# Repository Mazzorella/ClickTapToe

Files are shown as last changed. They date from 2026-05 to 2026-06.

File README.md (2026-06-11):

# ClickTapToe

ClickTapToe is a custom foot-operated mouse for people who need to reduce repetitive hand and arm movement. The goal is to move common mouse actions away from the hands by using foot pedals for clicking, a large foot-driven scroll wheel, and a separate mouse pointer module.

This repository contains the firmware, hardware notes, and project documentation for ClickTapToe. The current firmware target is a Seeed Studio XIAO nRF52840 / XIAO BLE running as a USB HID mouse with ZMK. Bluetooth is disabled for the ClickTapToe firmware build.

## Current Status

The current firmware supports USB mouse clicks from external pedals, USB vertical scrolling from the input hub scroll wheel, and pointer movement from the mouse pointer module:

- Left click on the first pedal input
- Right click on the second pedal input
- Vertical scroll from the AS5600 magnetic angle sensor connected to the input hub scroll wheel
- Pointer movement from the PMW3610 sensor in the mouse pointer module
- `D2` and `D3` remain spare/test inputs and are not exposed as production pedal jacks on the current input hub PCB

PMW3610 pointing support is active for the current firmware target.

## Hardware Overview

ClickTapToe is built from two custom electronics modules plus external pedals:

- The input hub contains the XIAO nRF52840 controller, USB connection, external pedal TS jacks, RJ45 pointer connection, and a large foot-operated scroll wheel coupled to an AS5600 magnetic angle sensor.
- The mouse pointer module is shaped like a slipper, houses a PMW3610 pointing sensor, and connects to the input hub over RJ45 with a short Ethernet cable.
- The pedals are premade external pedals connected to the input hub so higher-quality parts can be used and the project is easier to reproduce.

See [HARDWARE.md](HARDWARE.md) for the current pin map and hardware notes.
For a public-facing hardware overview with embedded board previews, open the
[ClickTapToe Hardware Viewer](https://mazzorella.github.io/ClickTapToe/).

| Board | Source | KiCanvas preview |
| --- | --- | --- |
| Input hub | [hardware/input-hub/](hardware/input-hub/) | [Open preview](https://mazzorella.github.io/ClickTapToe/hardware/input-hub/kicanvas.html) |
| Mouse pointer | [hardware/mouse-pointer/](hardware/mouse-pointer/) | [Open preview](https://mazzorella.github.io/ClickTapToe/hardware/mouse-pointer/kicanvas.html) |

## Repository Layout

- `.github/workflows/build.yml` runs the upstream ZMK user-config build workflow.
- `build.yaml` defines the firmware build matrix.
- `config/west.yml` tracks upstream ZMK and imports ZMK's west manifest.
- `zephyr/module.yml` declares this repository as the `zmk-keyboard-clicktaptoe` module and exposes its board, devicetree binding, Kconfig, and driver files.
- `boards/shields/clicktaptoe/` contains the ClickTapToe shield definition, overlay, metadata, and default keymap.
- `Makefile` wraps the local `west build` command for Docker/devcontainer use.
- `hardware/` contains the input hub and mouse pointer KiCad source files.
- `docs/` is reserved for assembly, usage, and release documentation.

## Build Target

The active firmware target is:

```yaml
board: xiao_ble//zmk
shield: clicktaptoe
artifact-name: clicktaptoe_xiao_usb_zmk
```

## Flashing

1. Build the firmware with GitHub Actions or a local ZMK toolchain.
2. Put the XIAO BLE into bootloader mode so it mounts as a UF2 drive.
3. Copy the generated `clicktaptoe_xiao_usb_zmk.uf2` file onto the mounted drive.
4. After the board reboots, connect it to the host over USB.

## Hardware Test

Use a safe desktop target for click testing, such as an empty Finder window or browser page.

- Short physical `D0` to `GND`; the host should receive a left click.
- Short physical `D1` to `GND`; the host should receive a right click.
- Rotate the AS5600 scroll wheel; the host should receive vertical scroll events.
- Move the mouse pointer module over a surface; the host pointer should move smoothly in the same direction.
- Test the PMW3610 once through the RJ45 cable path; pointer response should match the direct breadboard wiring test.
- Leave the AS5600 magnet away from the sensor once as a negative test; the host should not scroll continuously.
- Verify `D2` and `D3` only as spare/test GPIOs if they are wired for bring-up.

If macOS does not immediately recognize the updated HID device, unplug and reconnect the XIAO BLE.
If an old Bluetooth name appears after flashing, remove the cached Bluetooth entry from the host. This firmware build disables ZMK BLE.
If the PMW3610 does not move the pointer after flashing, power-cycle the XIAO once. The input hub physically routes PMW3610 `nRESET` on XIAO `D6` / RJ45 pin 8, but the current firmware still relies on SPI/software reset and does not drive that reset line yet.

## Local Build Notes

This repository is both a ZMK config repository and a ZMK module. Local builds should make the repository visible to ZMK as the config path and as an extra module so the custom `clicktaptoe` shield can be discovered.

The preferred local workflow is to build from a ZMK Docker/devcontainer environment and use this repository's `Makefile`.

One common local layout is to keep this repository next to a ZMK firmware checkout:

```text
projects/
  zmk/
  zmk-pmw3610-driver/
  ClickTapToe/
```

Open the ZMK firmware checkout in VS Code:

```sh
code /path/to/projects/zmk
```

Then use **Dev Containers: Reopen in Container**. If using a devcontainer, bind mount this repository into the container and run the build commands from the ClickTapToe repository directory.

On the first devcontainer launch, initialize the Zephyr workspace from the ZMK checkout:

```sh
west init -l app/
west update
```

Restart the devcontainer after `west update` completes.

Clone the PMW3610 driver module where the `Makefile` can find it. In the default devcontainer layout:

```sh
git clone https://github.com/badjeff/zmk-pmw3610-driver /workspaces/zmk-pmw3610-driver
```

After that, run the build commands from this repository:

```sh
make build
```

To build and copy the generated UF2 into this repository's `firmware/` directory:

```sh
make uf2
```

The copied firmware path is:

```sh
firmware/clicktaptoe_xiao_usb_zmk.uf2
```

Build outputs are written under this repository's ignored `build/` directory,
not under ZMK's `app/` tree.

By default, the `Makefile` expects ZMK's app directory to be available at `../zmk/app`, which matches the sibling directory layout shown above. Override `ZMK_APP` if your checkout path differs:

```sh
make uf2 ZMK_APP=/path/to/zmk/app
```

The wrapped `west` command has this shape:

```sh
west build -d "/path/to/this-repo/build/clicktaptoe" -b "xiao_ble//zmk" -- \
  -DSHIELD=clicktaptoe \
  -DZMK_CONFIG="/path/to/this-repo/config" \
  -DZMK_EXTRA_MODULES="/path/to/this-repo;/path/to/zmk-pmw3610-driver"
```

By default, the `Makefile` expects the PMW3610 driver module at `../zmk-pmw3610-driver`. Override `PMW3610_MODULE` if your checkout path differs:

```sh
make uf2 PMW3610_MODULE=/path/to/zmk-pmw3610-driver
```

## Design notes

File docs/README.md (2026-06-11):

# ClickTapToe Docs

This folder is reserved for project-level documentation such as assembly notes,
flashing instructions, bill of materials notes, and release documentation.

- [NEXT_STEPS.md](NEXT_STEPS.md) tracks deferred software and hardware follow-up
  work after the PCB hardware branch is merged back to `main`.

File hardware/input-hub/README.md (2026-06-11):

# Input Hub Hardware

This folder contains source files and notes for the ClickTapToe input hub PCB.

The input hub is the central electronics board. It hosts the XIAO nRF52840,
connects to the computer over USB, receives the external pedal TS jacks,
connects to the mouse pointer board over RJ45, and interfaces with the AS5600
scroll sensor.

## XIAO Pin Test Plan

This validation plan keeps the existing click pedals on `D0`/`D1`, uses the
AS5600 scroll sensor on the `D4`/`D5` I2C bus, and leaves the PMW3610 SPI
signals unchanged.

| XIAO pin | Signal plan | Firmware status |
| --- | --- | --- |
| `D0` | Left click pedal | Implemented |
| `D1` | Right click pedal | Implemented |
| `D2` | Future footswitch / TTS / spare input | Test direct GPIO input, emits play/pause |
| `D3` | Future footswitch / TTS / spare input | Test direct GPIO input, emits volume up |
| `D4` | AS5600 I2C bus | Implemented as `&xiao_i2c` |
| `D5` | AS5600 I2C bus | Implemented as `&xiao_i2c` |
| `D6` | PMW3610 `nRESET` | Implemented as active-low hardware reset |
| `D7` | PMW3610 `MOTION` | Implemented as PMW3610 interrupt |
| `D8` / `P1.13` | PMW3610 `SCLK` | Implemented |
| `D9` / `P1.14` | PMW3610 `nCS` | Implemented |
| `D10` / `P1.15` | PMW3610 `SDIO` | Implemented |

## Mouse Pointer RJ45 Pinout

The mouse pointer connector is an 8P8C modular jack used for ClickTapToe sensor
wiring. It is not Ethernet. The input hub RJ45 wiring must match the mouse
pointer board exactly.

| RJ45 pin | Signal | Input hub side |
| --- | --- | --- |
| 1 | `VIN` / `3V3` | 3.3 V sensor power |
| 2 | `GND` | Ground |
| 3 | `SCLK` | PMW3610 SPI clock |
| 4 | `SDIO` | PMW3610 bidirectional SPI data |
| 5 | `nCS` | PMW3610 chip select |
| 6 | `GND` | Ground |
| 7 | `MOTION` | PMW3610 motion interrupt |
| 8 | `nRESET` | PMW3610 reset routed to XIAO `D6` |

Twisted pair grouping:

| Pair | RJ45 pins | Signals |
| --- | --- | --- |
| Pair 1 | 1-2 | `VIN` / `3V3` + `GND` |
| Pair 2 | 3-6 | `SCLK` + `GND` |
| Pair 3 | 4-5 | `SDIO` + `nCS` |
| Pair 4 | 7-8 | `MOTION` + `nRESET` |

Series resistors for `SCLK`, `SDIO`, `nCS`, and `nRESET` belong on the input hub
side. The mouse pointer board only adds a local 100 ohm series resistor on
`MOTION`, and the input hub provides the `MOTION` pull-up to `3V3`.

`MOTION` is active-low and is handled by firmware on XIAO `D7`; the board also
has a 10k pull-up to `3V3` on that line.
`nRESET` is present in the cable on RJ45 pin 8 and is driven by firmware on XIAO
`D6` during PMW3610 initialization and retry.

## Online Review

`kicanvas.html` embeds the schematic and PCB in KiCanvas for browser-based
review. If GitHub Pages is enabled from the repository root, the input hub
viewer is available at:

```text
https://mazzorella.github.io/ClickTapToe/hardware/input-hub/kicanvas.html
```

## Planned Layout

- `kicad/` for KiCad project source files
- `kicad/production/` for generated Gerbers, drill files, BOMs, and placement files

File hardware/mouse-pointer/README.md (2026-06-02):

# Mouse Pointer Hardware

This folder contains source files and notes for the ClickTapToe mouse pointer
PCB.

The mouse pointer board contains the optical pointing sensor and connects to the
input hub over RJ45.

The initial KiCad source for this board is derived from the PMW3610 breakout by
`siderakb/pmw3610-pcb`. The current ClickTapToe revision preserves the original
PMW3610 optical/lens/LDO section while adding the project-specific RJ45 cable
interface.

Mouse Pointer 1.0 is the first ClickTapToe-maintained production revision of
this board.

## RJ45 Pinout

The connector is an 8P8C modular jack used for ClickTapToe sensor wiring. It is
not Ethernet.

| RJ45 pin | Signal | Notes |
| --- | --- | --- |
| 1 | `VIN` / `3V3` | Sensor board input power |
| 2 | `GND` | Ground return |
| 3 | `SCLK` | PMW3610 SPI clock |
| 4 | `SDIO` | PMW3610 bidirectional SPI data |
| 5 | `nCS` | PMW3610 chip select |
| 6 | `GND` | Ground return paired with `SCLK` |
| 7 | `MOTION` | Active-low PMW3610 motion output after local series resistor |
| 8 | `nRESET` | Reset routed from the input hub through a 0 ohm link |

Twisted pair grouping:

| Pair | RJ45 pins | Signals |
| --- | --- | --- |
| Pair 1 | 1-2 | `VIN` / `3V3` + `GND` |
| Pair 2 | 3-6 | `SCLK` + `GND` |
| Pair 3 | 4-5 | `SDIO` + `nCS` |
| Pair 4 | 7-8 | `MOTION` + `nRESET` |

## Board Configuration

- Default logic configuration is 3.3 V: `JP1` is a 0 ohm link from `VIN` to
  `VDDIO` and is installed by default.
- Alternate 1.8 V logic is available by populating `JP2`, a 0 ohm link from
  `+1V8` to `VDDIO`. `JP2` is DNP by default.
- `JP3` is a 0 ohm reset link from RJ45 `nRESET` to PMW3610 `nRESET` and is
  installed by default.
- `R3` is a 100 ohm series resistor on `MOTION`, placed near the PMW3610 side
  before the signal leaves the board.
- `R2` is a 100k optional `nCS` pull-up to `VDDIO` and is DNP by default.
- `J1` remains as a debug/test header on the PMW3610-side signals.
- `U3` and `U4` are TPD4E05U06DQAR ESD protection arrays on the RJ45-facing
  cable signals.

The RJ45 connector is unshielded and is intended for hand installation. `J1` is
also optional/test-only and is not assigned a JLCPCB part number in the
production BOM.

The current firmware handles `MOTION` on XIAO `D7` through RJ45 pin 7 and
pulses `nRESET` on XIAO `D6` through RJ45 pin 8 before PMW3610 initialization.

## Online Review

`kicanvas.html` embeds the schematic and PCB in KiCanvas for browser-based
review. If GitHub Pages is enabled from the repository root, the mouse pointer
viewer is available at:

```text
https://mazzorella.github.io/ClickTapToe/hardware/mouse-pointer/kicanvas.html
```

## Planned Layout

- `kicad/` for KiCad project source files
- `production/` for generated Gerbers, drill files, BOMs, and placement files

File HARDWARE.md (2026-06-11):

# ClickTapToe Hardware Notes

This file tracks the hardware assumptions used by the firmware.

## Controller

- Controller: Seeed Studio XIAO nRF52840 / XIAO BLE
- ZMK board target: `xiao_ble//zmk`
- Connection mode: USB HID; ZMK BLE disabled

## Current Pedal Inputs

The current firmware uses direct GPIO inputs. Yamaha-style pedals short the
signal pin to `GND` at rest and open when pressed, so the firmware enables
internal pull-ups and treats the inputs as active-high.

For the next input hub PCB revision, add an optional 0 ohm jumper from each
pedal jack's tip-normal contact to `GND`. Populate this jumper for normally
closed Yamaha-style pedals so an unplugged jack is forced idle instead of
looking like a pressed pedal. Leave it DNP for normally open pedals and use the
matching active-low firmware polarity.

Known jack normal contacts:

| Jack type | Routed signal contact | Normal contact to optionally ground |
| --- | --- | --- |
| 1/4 inch Amphenol `ACJM-IH` | `T` / tip | `TN` / tip-normal |
| 3.5 mm `PJ-307` | Pin 5 | Pin 4 |

| Function | XIAO pin | ZMK binding | Status |
| --- | --- | --- | --- |
| Left click pedal | `D0` | `&mkp LCLK` | Implemented |
| Right click pedal | `D1` | `&mkp RCLK` | Implemented |
| Future footswitch / TTS / spare input | `D2` | `&kp C_PLAY_PAUSE` | Test direct GPIO input |
| Future footswitch / TTS / spare input | `D3` | `&kp C_VOL_UP` | Test direct GPIO input |

## Current Scroll Input

The current firmware supports vertical scroll with an AS5600 magnetic angle
sensor in the input hub. The scroll wheel spins freely with a diametric magnet
mounted on the wheel shaft near the sensor.

| Function | XIAO pin | Status |
| --- | --- | --- |
| AS5600 I2C bus | `D4` | Implemented as `&xiao_i2c` |
| AS5600 I2C bus | `D5` | Implemented as `&xiao_i2c` |
| AS5600 `VCC` | `3V3` | Board routed |
| AS5600 `GND` | `GND` | Board routed |

The AS5600 uses fixed I2C address `0x36`. ZMK is configured with
`triggers-per-rotation = <24>` as the starting scroll sensitivity for bring-up;
this should be tuned once the wheel, shaft, magnet, and sensor are mounted in
their final positions.

## Current Pointing Input

The current firmware supports PMW3610 pointing from the mouse pointer module over the XIAO SPI bus. The PMW3610 uses a bidirectional `SDIO` pin, so firmware maps both SPI MOSI and MISO to XIAO `D10`.

| Function | XIAO pin | PMW3610 pin | RJ45 pin / color | Status |
| --- | --- | --- | --- | --- |
| Sensor power | `3V3` | `VIN` / `VDDIO` default | `1` / white-orange | Board routed |
| Sensor ground | `GND` | `GND` | `2` / orange, `6` / green | Board routed |
| SPI clock | `D8` / `P1.13` | `SCLK` | `3` / white-green | Board routed |
| SPI data | `D10` / `P1.15` | `SDIO` | `4` / blue | Board routed |
| Chip select | `D9` / `P1.14` | `nCS` | `5` / white-blue | Board routed |
| Motion interrupt | `D7` / `P1.12` | `MOTION` | `7` / white-brown | Board routed |
| Sensor reset | `D6` | `nRESET` | `8` / brown | Board routed; current firmware uses SPI/software reset |

The mouse pointer module connects to the input hub through an 8P8C modular jack
used as a ClickTapToe sensor cable, not Ethernet. The cable pairing is:

| Pair | RJ45 pins | Signals |
| --- | --- | --- |
| Pair 1 | 1-2 | `VIN` / `3V3` + `GND` |
| Pair 2 | 3-6 | `SCLK` + `GND` |
| Pair 3 | 4-5 | `SDIO` + `nCS` |
| Pair 4 | 7-8 | `MOTION` + `nRESET` |

The PMW3610 orientation is corrected in firmware with `swap-xy` and `invert-y`.
The mouse pointer board routes `nRESET` over RJ45, and the input hub connects it
to XIAO `D6`. The input hub also provides a 10k pull-up to `3V3` on the
active-low `MOTION` interrupt line. This validated firmware build keeps the
original PMW3610 driver behavior and relies on SPI/software reset; D6 is routed
for a later hardware-reset recovery update.

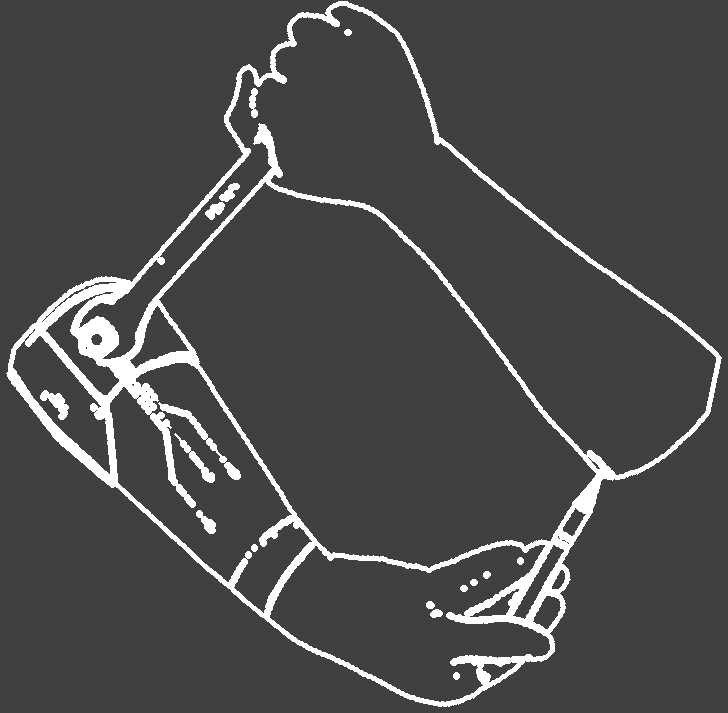
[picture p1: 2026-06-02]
hardware/input-hub/kicad/assets/empower-hand-line-silkscreen-mildsmooth.png

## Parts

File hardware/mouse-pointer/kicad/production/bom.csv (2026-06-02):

Designator | Footprint | Quantity | Value | LCSC Part #
C1 | 0805 | 1 | 3.3uF/16V | C7393948
C2, C3, C4 | 0603 | 3 | 100nF | C14663
C5, C7 | 0603 | 2 | 10nF | C57112
C6 | 0805 | 1 | 10uF | C15850
C8, C9 | 0603 | 2 | 1uF | C15849
JP1, JP3 | 0603 | 2 | 0R | C21189
R1 | 0603 | 1 | 10k | C25804
R3 | 0603 | 1 | 100 | C22775
U1 | PMW3610DM-SUDU 16Pin | 1 | PMW3610 | C42442560
U2 | SOT-23-5_HandSoldering | 1 | TLV74318PDBVR | C485152
U3, U4 | IC_TPD4E05U06DQAR | 2 | TPD4E05U06DQAR | C138714

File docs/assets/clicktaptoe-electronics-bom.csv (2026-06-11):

Quantity | Value | Footprint | LCSC Part # | Used on
4 | 1u | 0603 | C15849 | Input hub C1 C3; mouse pointer C8 C9
2 | 10uF | 0805 | C15850 | Input hub C2; mouse pointer C6
1 | 1206L012WR | 1206 | C151160 | Input hub F1
1 | B2B-PH-SM4-TB | JST_PH_B2B-PH-SM4-TB_1x02-1MP_P2.00mm_Vertical | C160352 | Input hub J11
1 | BM04B-SRSS-TB_LF__SN_ | JST_BM04B-SRSS-TB_LF__SN_ | C160390 | Input hub J5
2 | 330 | 0603 | C23138 | Input hub R1 R2
3 | 47R | 0603 | C23182 | Input hub R3 R4 R5
2 | 100 | 0603 | C22775 | Input hub R6; mouse pointer R3
4 | 10k | 0603 | C25804 | Input hub R7 R8 R9; mouse pointer R1
4 | TPD4E05U06DQAR | IC_TPD4E05U06DQAR | C138714 | Input hub U2 U3; mouse pointer U3 U4
1 | 3.3uF/16V | 0805 | C7393948 | Mouse pointer C1
3 | 100nF | 0603 | C14663 | Mouse pointer C2 C3 C4
2 | 10nF | 0603 | C57112 | Mouse pointer C5 C7
2 | 0R | 0603 | C21189 | Mouse pointer JP1 JP3
1 | PMW3610 | PMW3610DM-SUDU 16Pin | C42442560 | Mouse pointer U1
1 | TLV74318PDBVR | SOT-23-5_HandSoldering | C485152 | Mouse pointer U2

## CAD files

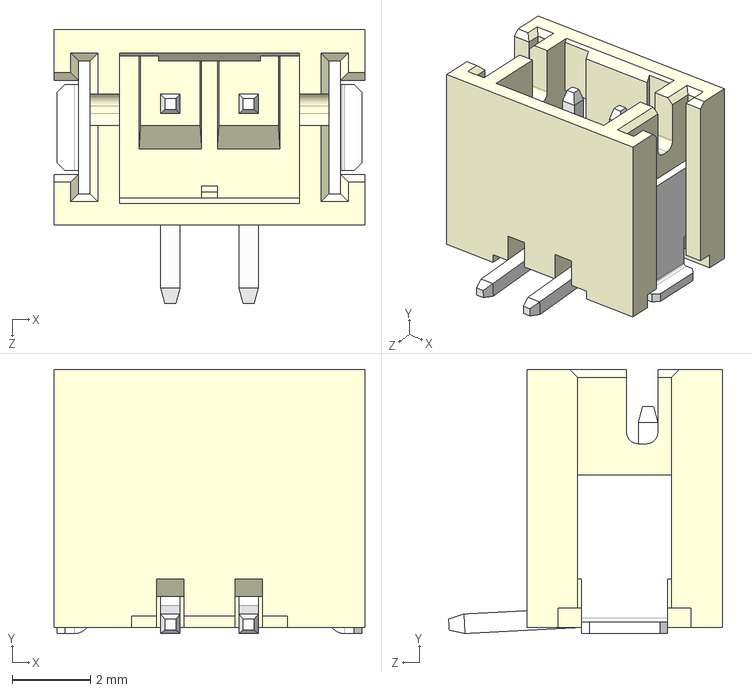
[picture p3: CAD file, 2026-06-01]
hardware/input-hub/kicad/3dmodels/B2B-PH-SM4-TB.step
7.95 x 6.75 x 7.00 mm

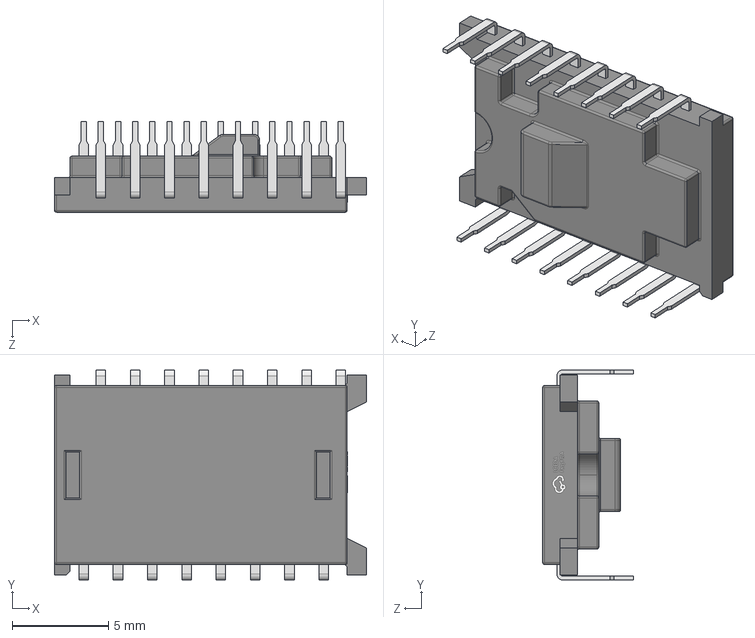
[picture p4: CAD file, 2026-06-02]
hardware/mouse-pointer/kicad/3dmodels/PMW3610DM-SUDU.step
16.2 x 10.9 x 4.70 mm

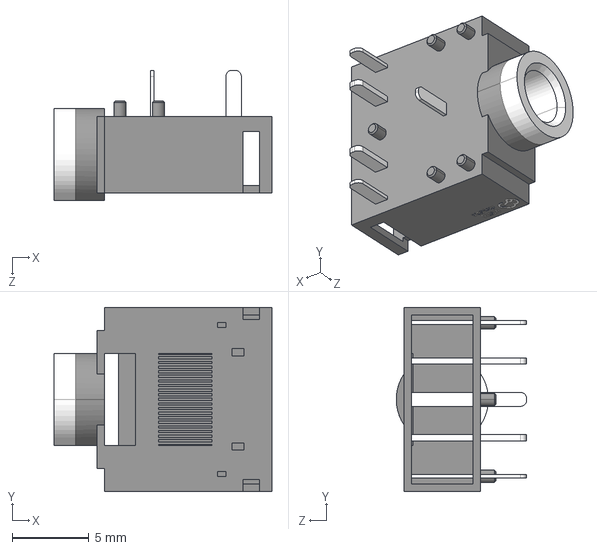
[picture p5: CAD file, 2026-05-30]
hardware/input-hub/kicad/3dmodels/AUDIO-TH_PJ-307.step
14.2 x 12.0 x 8.50 mm

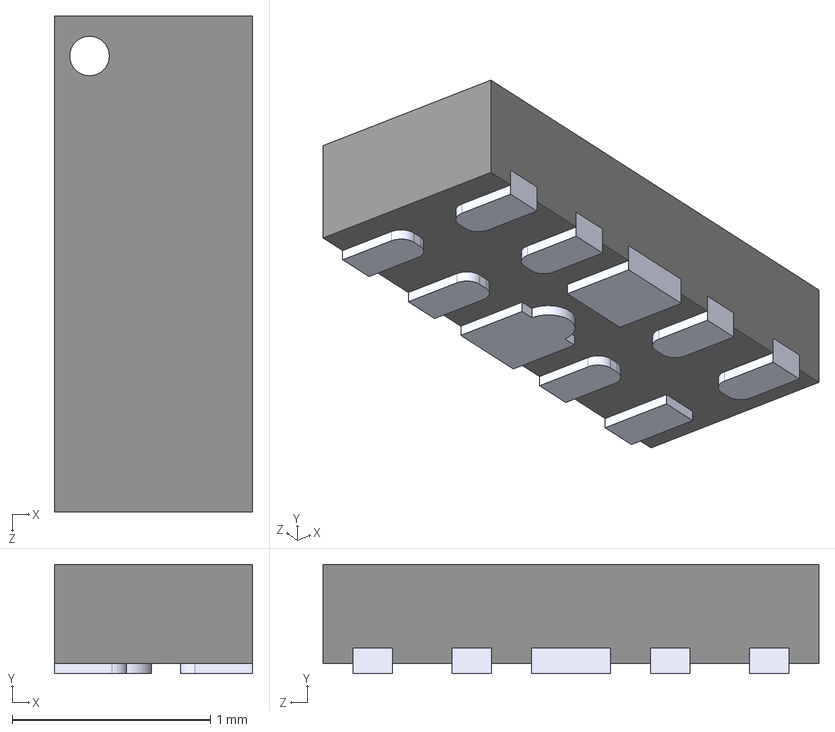
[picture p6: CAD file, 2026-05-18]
hardware/mouse-pointer/kicad/3dmodels/TPD4E05U06DQAR.step
1.00 x 0.55 x 2.50 mm

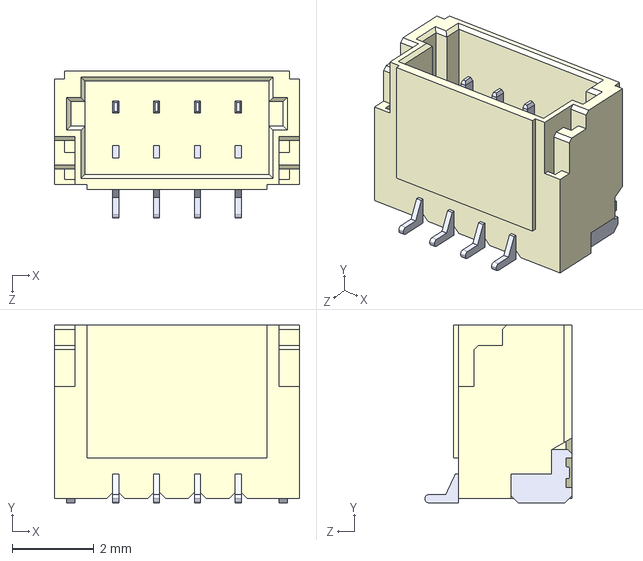
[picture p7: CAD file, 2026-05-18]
hardware/input-hub/kicad/3dmodels/BM04B-SRSS-TB_LF__SN_.step
6.00 x 4.35 x 3.60 mm

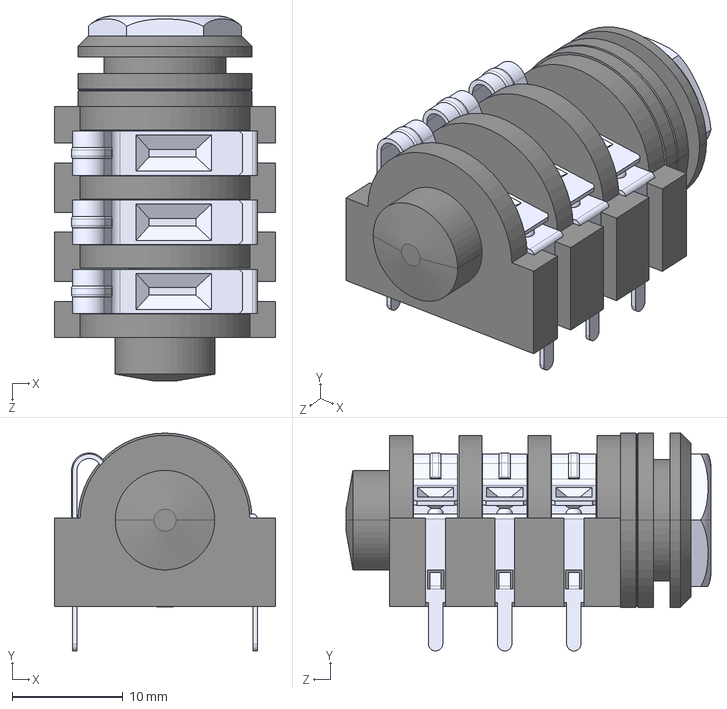
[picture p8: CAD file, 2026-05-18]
hardware/input-hub/kicad/3dmodels/ACJMIH.step
20.0 x 19.7 x 33.0 mm

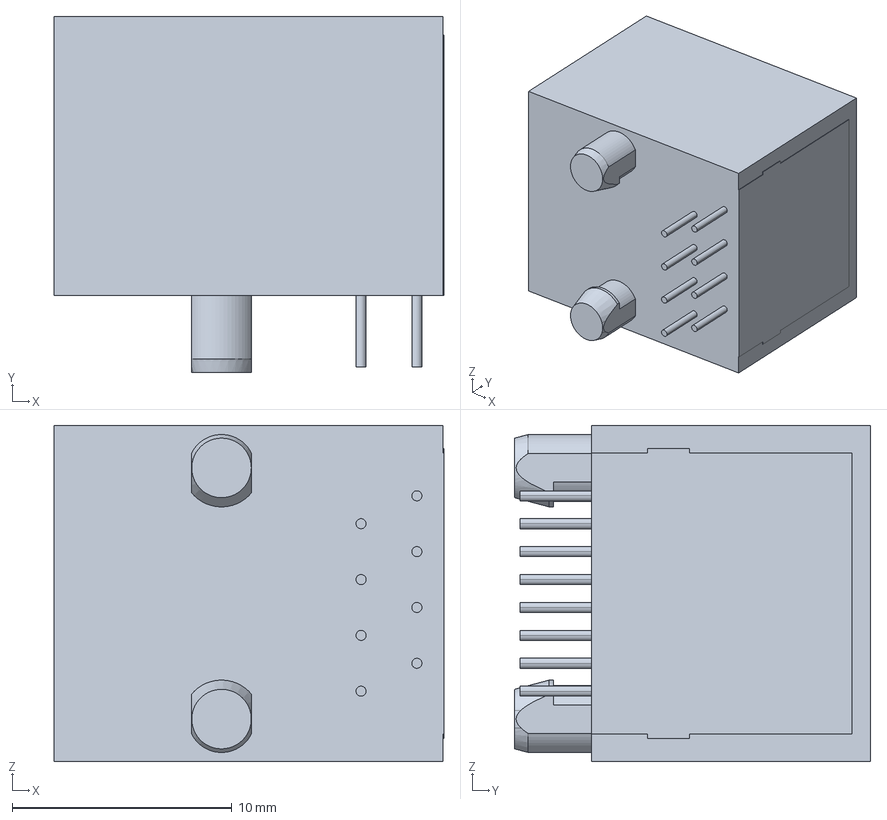
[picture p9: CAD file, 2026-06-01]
hardware/mouse-pointer/kicad/3dmodels/54602-908LFc.stp
17.7 x 16.2 x 15.3 mm

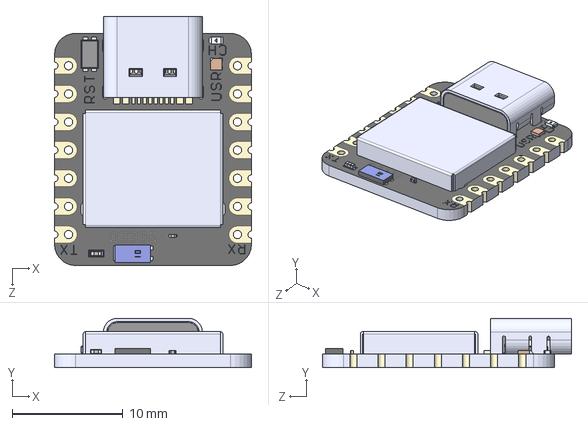
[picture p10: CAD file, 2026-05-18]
hardware/input-hub/kicad/3dmodels/102010448.step
17.8 x 4.46 x 22.5 mm

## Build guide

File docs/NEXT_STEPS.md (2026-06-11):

# Next Steps

These items are intentionally deferred until after the PCB hardware work is
merged back to `main`.

## Software

- Continue the PMW3610 motion-detection and reset-retry work from the driver
  repository stash:

  ```sh
  cd /Users/michael/Documents/School/EMPOWER/zmk-pmw3610-driver
  git stash show -p stash@{0}
  ```

- The stash is currently:

  ```text
  stash@{0}: On clicktaptoe-hotplug-reset: clicktaptoe-pmw-reset-retry-work
  ```

- Re-apply it on a new branch from the updated `main` integration path when
  that work resumes:

  ```sh
  git stash apply stash@{0}
  ```

## Hardware

- Integrate the XIAO battery access footprint in a future input hub hardware
  update.
- The footprint is currently preserved in this repository's local stash:

  ```text
  stash@{0}: On pcb-hardware: XIAO battery access footprint
  ```

- It contains:

  ```text
  hardware/input-hub/kicad/input_hub.pretty/XIAO_BAT_SOLDER_ACCESS.kicad_mod
  ```

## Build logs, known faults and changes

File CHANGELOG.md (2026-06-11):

# Changelog

All notable changes to this project will be documented in this file.

The format is based on Keep a Changelog, and this project uses semantic versioning with tags in the form `vX.Y.Z`.

## [Unreleased]

### Firmware

- Restore the validated USB HID ClickTapToe firmware configuration for the
  working input hub PCB.
- Add AS5600 magnetic scroll sensor support for the input hub scroll wheel.
- Add XIAO onboard status LED activity reporting for bring-up feedback.

### Hardware

- Add ClickTapToe-maintained KiCad source for the mouse pointer PCB.
- Add KiCad source, JLC assembly preparation, production files, 3D models, and
  KiCanvas previews for the input hub PCB.
- Add RJ45 wiring between the input hub and mouse pointer module, including
  PMW3610 power, SPI, motion interrupt, and reset routing.
- Add ESD protection, alternate pedal jack footprints, updated connector
  layout, silkscreen artwork, and production output refinements.
- Document the next input hub pedal jack normal-contact grounding improvement.

### Documentation

- Add the public hardware viewer page with board images, embedded KiCanvas
  previews, fabrication downloads, a combined electronics BOM, assembly
  guidance, and the RJ45 pinout.
- Add follow-up notes for the deferred PMW3610 reset-retry driver stash and the
  stashed XIAO battery access footprint.

## [0.3.1] - 2026-05-14

### Documentation

- Add contributing notes for commit style, branch policy, releases, and changelog updates.
- Standardize hardware board naming around the input hub and mouse pointer modules.

### Hardware

- Replace the old placeholder hardware folders with input-hub and mouse-pointer placeholders.
- Add a per-folder CERN-OHL-P v2 license placeholder for future input-hub hardware source.

## [0.3.0] - 2026-04-30

### Firmware

- Add PMW3610 pointing support on the XIAO SPI bus for the right-foot module.
- Add the external `badjeff/zmk-pmw3610-driver` module to the west manifest.
- Force the ClickTapToe build to USB HID mode with ZMK BLE disabled.
- Add a PMW3610 startup delay for the no-reset sensor wiring.

### Hardware

- Document the no-reset PMW3610 RJ45 pinout for the right-foot pointing module.
- Validate PMW3610 pointing over the RJ45 cable path.

## [0.2.0] - 2026-04-29

### Firmware

- AS5600 magnetic scroll wheel support for USB vertical scrolling.
- Documentation for the AS5600 scroll pin map and hardware test steps.

### Hardware

- No hardware design files changed.

## [0.1.0] - 2026-04-29

### Firmware

- Initial ClickTapToe ZMK shield for the Seeed Studio XIAO nRF52840 / XIAO BLE.
- USB mouse click support for left and right foot pedals.
- Hardware notes for known pedal GPIOs and reserved future inputs.
- Local `Makefile` wrapper for ZMK `west build`.
- GitHub Actions build workflow using the upstream ZMK user-config workflow.

### Hardware

- No hardware design files included yet.

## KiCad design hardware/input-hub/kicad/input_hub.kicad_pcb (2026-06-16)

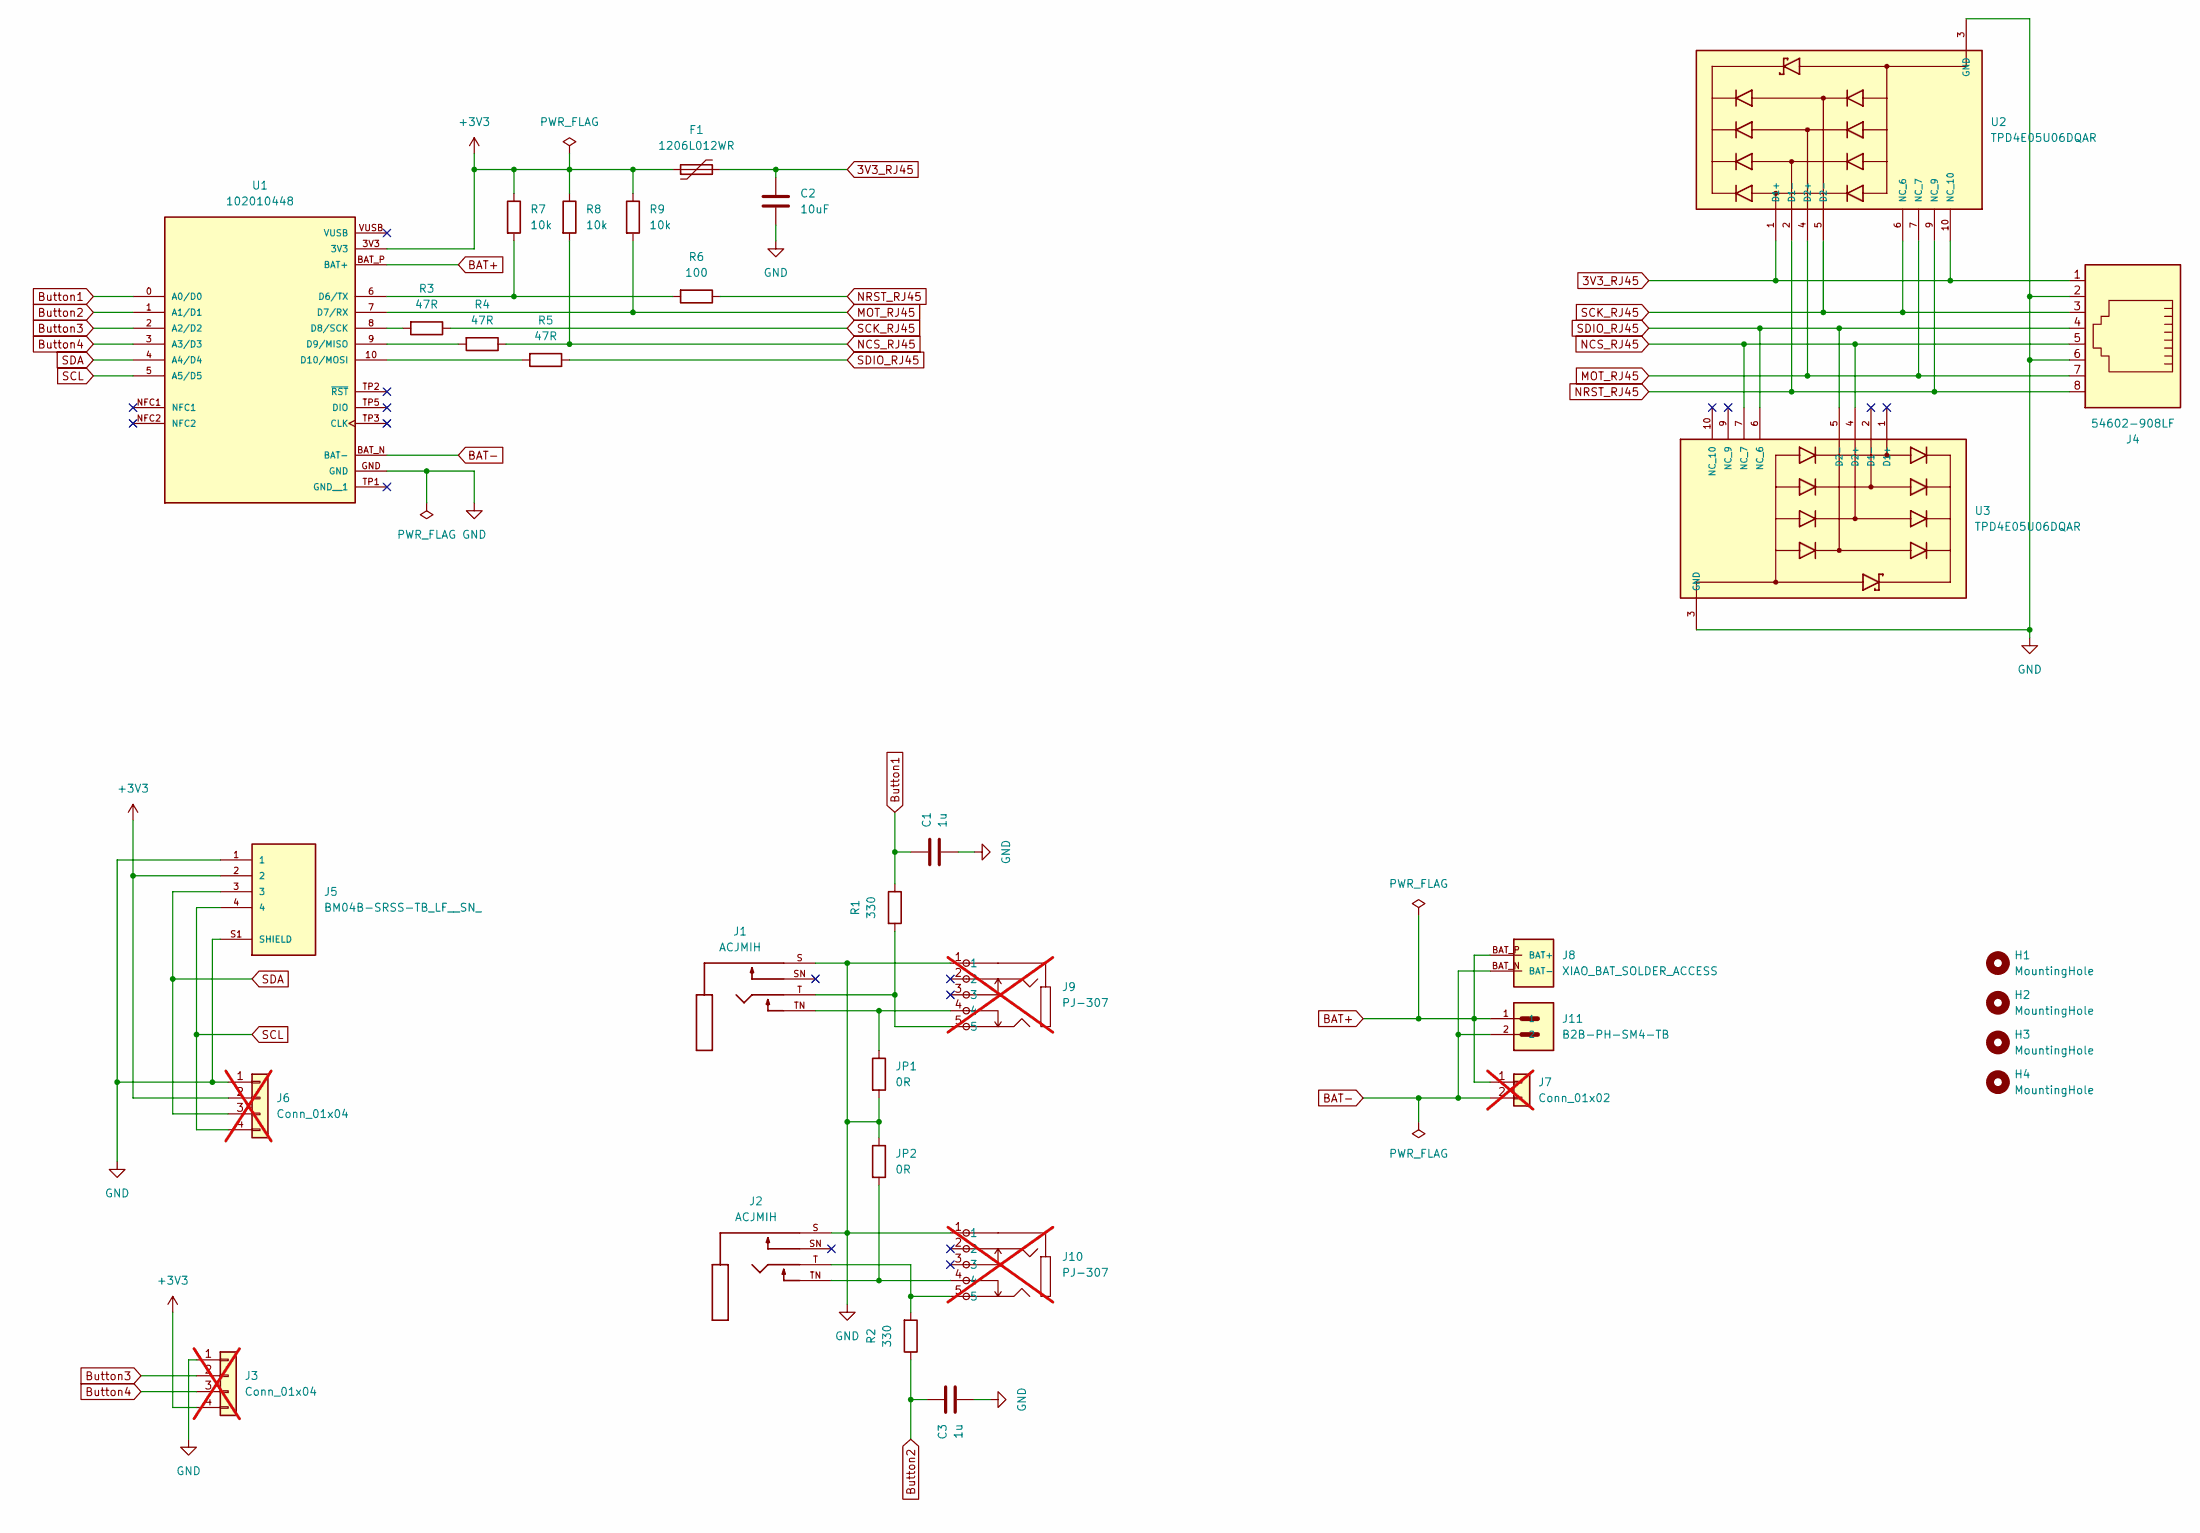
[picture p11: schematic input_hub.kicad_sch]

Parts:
C1, C3: 1u; C_0603_1608Metric; JLCPCB Part # C15849
C2: 10uF; C_0805_2012Metric; JLCPCB Part # C15850
F1: 1206L012WR; Fuse_1206_3216Metric; JLCPCB Part # C151160
H1, H2, H3, H4: MountingHole; MountingHole_3.2mm_M3_ISO14580
J1, J2: ACJMIH; AMPHENOL_ACJMIH; PARTREV 2; DigiKey_Part_Number 889-ACJM-IH-ND
J3, J6: Conn_01x04; PinHeader_1x04_P2.54mm_Vertical; not fitted
J4: 54602-908LF; RJ45_Amphenol_54602-x08_Horizontal; MFR. Part # 54602-908LF; Digi-Key MFR. Part # 54602-908LF
J5: BM04B-SRSS-TB_LF__SN_; JST_BM04B-SRSS-TB_LF__SN_; PARTREV N/A; JLCPCB Part # C160390
J7: Conn_01x02; PinHeader_1x02_P2.54mm_Vertical; not fitted
J8: XIAO_BAT_SOLDER_ACCESS
J9, J10: PJ-307; AUDIO-TH_PJ-307; MPN PJ-307; LCSC Part C2939173; not fitted
J11: B2B-PH-SM4-TB; JST_PH_B2B-PH-SM4-TB_1x02-1MP_P2.00mm_Vertical; MFR. Part # B2B-PH-SM4-TB(LF)(SN); JLCPCB Part # C160352
JP1, JP2: 0R; R_0603_1608Metric; JLCPCB Part # C21189
R1, R2: 330; R_0603_1608Metric; JLCPCB Part # C23138
R3, R4, R5: 47R; R_0603_1608Metric; JLCPCB Part # C23182
R6: 100; R_0603_1608Metric; JLCPCB Part # C22775
R7, R8, R9: 10k; R_0603_1608Metric; JLCPCB Part # C25804
U1: 102010448; MODULE_102010448; PARTREV 2022/08/18; Digi-Key MFR. Part # 102010448
U2, U3: TPD4E05U06DQAR; IC_TPD4E05U06DQAR; PARTREV N; JLCPCB Part # C138714

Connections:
3V3_RJ45: C2.2, F1.2, J4.1, U2.1 (D1+), U2.10 (NC_10)
+3V3: F1.1, J3.4, J5.2, J6.2, R7.1, R8.1, R9.1, U1.3V3
BAT+: J7.1, J8.BAT_P (BAT+), J11.1, U1.BAT_P (BAT+)
BAT-: J7.2, J8.BAT_N (BAT-), J11.2, U1.BAT_N (BAT-)
Button1: C1.2, R1.1, U1.0 (A0/D0)
Button2: C3.2, R2.1, U1.1 (A1/D1)
Button3: J3.2, U1.2 (A2/D2)
Button4: J3.3, U1.3 (A3/D3)
GND: C1.1, C2.1, C3.1, J1.S, J2.S, J3.1, J4.2, J4.6, J5.1, J5.S1 (SHIELD), J5.S2 (SHIELD), J6.1, J9.1, J10.1, JP1.2, JP2.1, U1.GND, U2.3 (GND), U2.8 (GND), U3.3 (GND), U3.8 (GND)
MOT_RJ45: J4.7, R9.2, U1.7 (D7/RX), U2.4 (D2+), U2.7 (NC_7)
NCS_RJ45: J4.5, R4.1, R8.2, U3.4 (D2+), U3.7 (NC_7)
NRST_RJ45: J4.8, R6.1, U2.2 (D1-), U2.9 (NC_9)
unnamed: J1.T, J9.5, R1.2
unnamed: J1.TN, J9.4, JP1.1
unnamed: J2.TN, J10.4, JP2.2
unnamed: J2.T, J10.5, R2.2
unnamed: R6.2, R7.2, U1.6 (D6/TX)
unnamed: R3.2, U1.8 (D8/SCK)
unnamed: R4.2, U1.9 (D9/MISO)
unnamed: R5.2, U1.10 (D10/MOSI)
SCK_RJ45: J4.3, R3.1, U2.5 (D2-), U2.6 (NC_6)
SCL: J5.4, J6.4, U1.5 (A5/D5)
SDA: J5.3, J6.3, U1.4 (A4/D4)
SDIO_RJ45: J4.4, R5.1, U3.5 (D2-), U3.6 (NC_6)

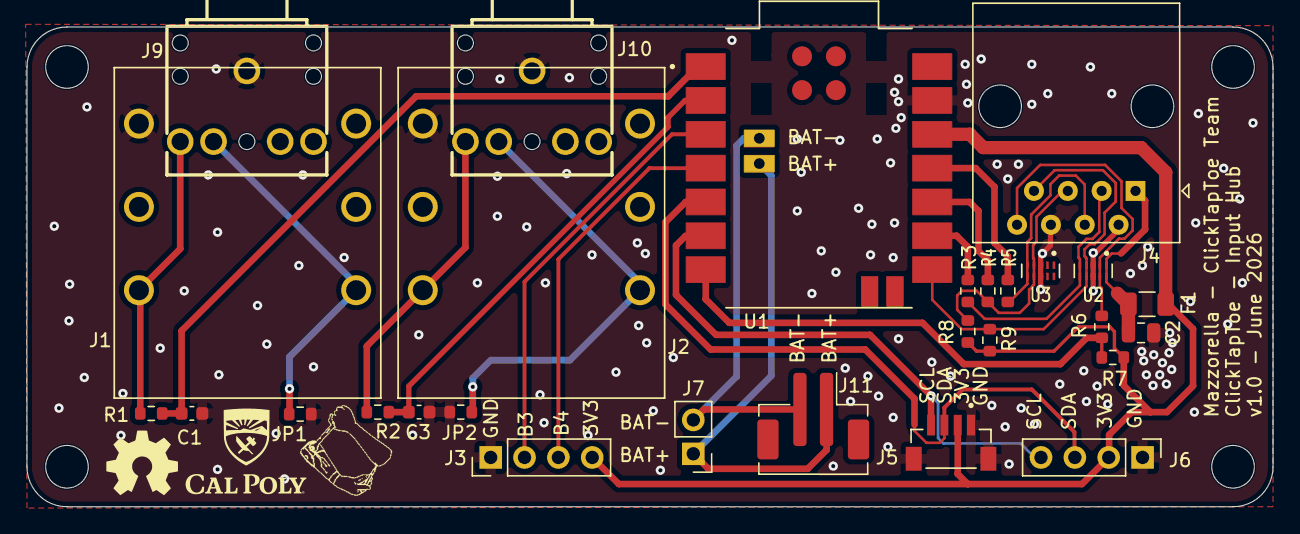
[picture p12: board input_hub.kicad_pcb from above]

Board: 2 copper layers, 93.5 x 36.0 mm, 33 parts (0 on the bottom side), 24 nets.

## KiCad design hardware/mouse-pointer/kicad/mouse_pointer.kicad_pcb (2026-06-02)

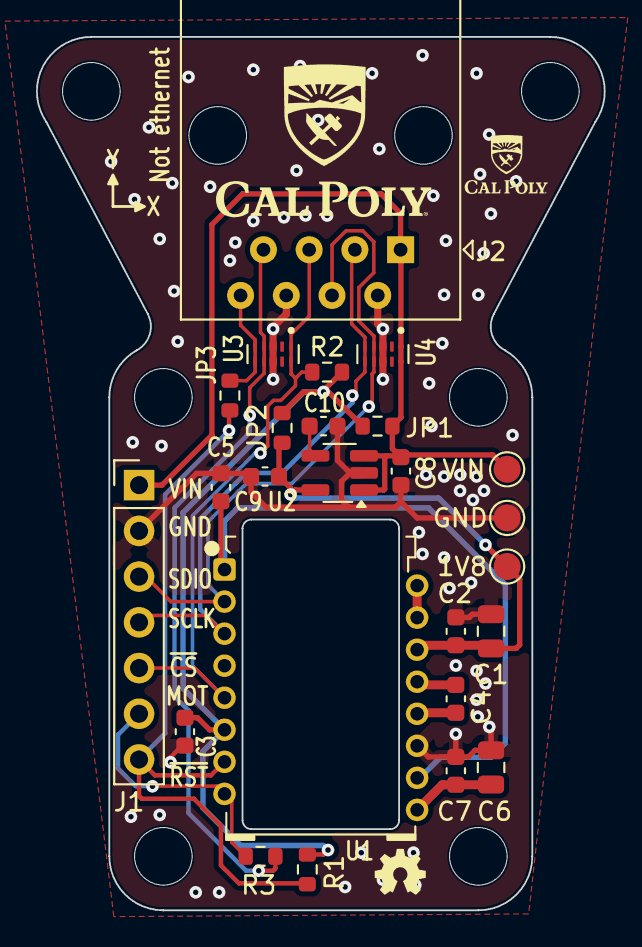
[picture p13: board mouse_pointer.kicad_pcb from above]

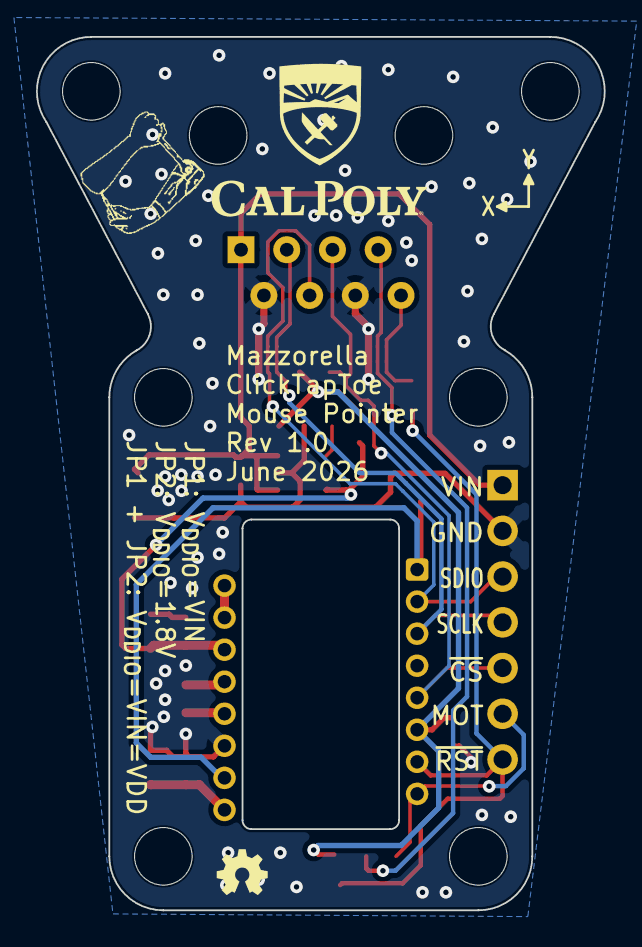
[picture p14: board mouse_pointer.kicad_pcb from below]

Board: 2 copper layers, 31.5 x 48.5 mm, 31 parts (3 on the bottom side), 17 nets.

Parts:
C1: 3.3uF/16V; C_0805_2012Metric
C2, C3, C4: 100nF; C_0603_1608Metric
C5, C7: 10nF; C_0603_1608Metric
C6: 10uF; C_0805_2012Metric
C8, C9: 1uF; C_0603_1608Metric
C10: 22nF; C_0603_1608Metric
H1, H2, H3, H4, H5, H6: MountingHole; MountingHole_3.2mm_M3_ISO14580
J1: Conn_PinHeader; PinHeader_1x07_P2.54mm_Vertical
J2: 54602-908LF; RJ45_Amphenol_54602-x08_Horizontal
JP1, JP2, JP3: 0R; R_0603_1608Metric
R1: 10k; R_0603_1608Metric
R2: 100k; R_0603_1608Metric
R3: 100; R_0603_1608Metric
TP1, TP2, TP3: TestPoint; TestPoint_Pad_D1.5mm
U1: PMW3610; PMW3610DM-SUDU 16Pin
U2: TLV74318PDBVR; SOT-23-5_HandSoldering
U3, U4: TPD4E05U06DQAR; IC_TPD4E05U06DQAR

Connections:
+1V8: C1.1, C2.1, C9.1, JP2.2, TP3.1 (1_1), U1.14 (VDD), U2.5 (OUT)
GND: C1.2, C2.2, C3.2, C5.2, C6.2, C7.2, C8.2, C9.2, C10.2, J1.2, J2.2, J2.6, TP2.1 (1_1), U1.11 (GND), U2.2 (GND), U3.3 (GND), U3.8 (GND), U4.3 (GND), U4.8 (GND)
MOTION: J1.6, R3.1, U1.8 (MOTION)
MOT_RJ45: J2.7, R3.2, U3.4 (D2+), U3.7 (NC_7)
unnamed: C5.1, U1.1 (+VCSEL), U1.10 (PASS_T)
unnamed: U1.15 (XYLASER), U1.16 (-VCSEL)
unnamed: C4.2, U1.13 (CN)
unnamed: C4.1, U1.12 (CP)
unnamed: C6.1, C7.1, U1.9 (VCP)
unnamed: C10.1, U2.4 (NC)
SCLK: J1.4, J2.3, U1.3 (SCLK), U4.5 (D2-), U4.6 (NC_6)
SDIO: J1.3, J2.4, U1.2 (SDIO), U4.4 (D2+), U4.7 (NC_7)
VDDIO: C3.1, JP1.2, JP2.1, R1.1, R2.1, U1.6 (VDDIO)
VIN: C8.1, J1.1, J2.1, JP1.1, TP1.1 (1_1), U2.1 (IN), U2.3 (EN), U4.1 (D1+), U4.10 (NC_10)
nCS: J1.5, J2.5, R2.2, U1.5 (NCS), U3.1 (D1+), U3.10 (NC_10)
nRESET: J1.7, JP3.1, R1.2, U1.7 (NRESET)
nRST_RJ45: J2.8, JP3.2, U3.5 (D2-), U3.6 (NC_6)

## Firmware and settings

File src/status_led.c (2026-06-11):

/*
 * Copyright (c) 2026 ClickTapToe contributors
 *
 * SPDX-License-Identifier: MIT
 */

#include <zephyr/device.h>
#include <zephyr/devicetree.h>
#include <zephyr/drivers/gpio.h>
#include <zephyr/drivers/i2c.h>
#include <zephyr/drivers/sensor.h>
#include <zephyr/drivers/spi.h>
#include <zephyr/init.h>
#include <zephyr/input/input.h>
#include <zephyr/kernel.h>
#include <zephyr/logging/log.h>
#include <zephyr/sys/util.h>

#include <zephyr/dt-bindings/input/input-event-codes.h>

#include <zmk/event_manager.h>
#include <zmk/events/position_state_changed.h>
#include <zmk/events/sensor_event.h>

LOG_MODULE_REGISTER(clicktaptoe_status_led, CONFIG_CLICKTAPTOE_STATUS_LED_LOG_LEVEL);

#define RED_LED_NODE DT_ALIAS(led0)
#define GREEN_LED_NODE DT_ALIAS(led1)
#define BLUE_LED_NODE DT_ALIAS(led2)

#define HAS_STATUS_LEDS                                                                           \
    (DT_NODE_HAS_STATUS(RED_LED_NODE, okay) && DT_NODE_HAS_STATUS(GREEN_LED_NODE, okay) &&         \
     DT_NODE_HAS_STATUS(BLUE_LED_NODE, okay))

#define AS5600_NODE DT_NODELABEL(scroll_as5600)
#define PMW3610_NODE DT_NODELABEL(pmw3610)
#define AS5600_STATUS_REGISTER 0x0B
#define PMW3610_PRODUCT_ID_REGISTER 0x00
#define PMW3610_PRODUCT_ID 0x3E
#define PMW3610_SPI_MODE (SPI_OP_MODE_MASTER | SPI_WORD_SET(8) | SPI_MODE_CPOL | SPI_MODE_CPHA |   \
                          SPI_TRANSFER_MSB)

#if HAS_STATUS_LEDS

static const struct gpio_dt_spec red_led = GPIO_DT_SPEC_GET(RED_LED_NODE, gpios);
static const struct gpio_dt_spec green_led = GPIO_DT_SPEC_GET(GREEN_LED_NODE, gpios);
static const struct gpio_dt_spec blue_led = GPIO_DT_SPEC_GET(BLUE_LED_NODE, gpios);
#if DT_NODE_HAS_STATUS(AS5600_NODE, okay)
static const struct i2c_dt_spec as5600_i2c = I2C_DT_SPEC_GET(AS5600_NODE);
#endif
#if DT_NODE_HAS_STATUS(PMW3610_NODE, okay)
static const struct spi_dt_spec pmw3610_spi = SPI_DT_SPEC_GET(PMW3610_NODE, PMW3610_SPI_MODE, 0);
#endif

static struct k_work_delayable health_check_work;
static struct k_work_delayable error_blink_work;
static struct k_work_delayable activity_off_work;

static bool health_initialized;
static bool health_error;
static bool error_blink_on;

static int set_led(const struct gpio_dt_spec *led, bool on) {
    int err = gpio_pin_set_dt(led, on);

    if (err) {
        LOG_WRN("Failed to set status LED: %d", err);
    }

    return err;
}

static void set_all_leds_off(void) {
    (void)set_led(&red_led, false);
    (void)set_led(&green_led, false);
    (void)set_led(&blue_led, false);
}

static bool required_devices_ready(void) {
#if DT_NODE_HAS_STATUS(AS5600_NODE, okay)
    if (!i2c_is_ready_dt(&as5600_i2c)) {
        LOG_WRN("AS5600 I2C bus is not ready");
        return false;
    }

    uint8_t status;
    int err = i2c_reg_read_byte_dt(&as5600_i2c, AS5600_STATUS_REGISTER, &status);
    if (err) {
        LOG_WRN("AS5600 scroll device probe failed: %d", err);
        return false;
    }
#endif

#if DT_NODE_HAS_STATUS(PMW3610_NODE, okay)
    if (!spi_is_ready_dt(&pmw3610_spi)) {
        LOG_WRN("PMW3610 SPI bus is not ready");
        return false;
    }

    uint8_t reg = PMW3610_PRODUCT_ID_REGISTER;
    uint8_t product_id = 0;
    const struct spi_buf tx_buf = {.buf = &reg, .len = sizeof(reg)};
    const struct spi_buf_set tx = {.buffers = &tx_buf, .count = 1};
    struct spi_buf rx_buf[] = {
        {.buf = NULL, .len = sizeof(reg)},
        {.buf = &product_id, .len = sizeof(product_id)},
    };
    const struct spi_buf_set rx = {.buffers = rx_buf, .count = ARRAY_SIZE(rx_buf)};
    int pmw_err = spi_transceive_dt(&pmw3610_spi, &tx, &rx);
    if (pmw_err) {
        LOG_WRN("PMW3610 pointer device probe failed: %d", pmw_err);
        return false;
    }

    if (product_id != PMW3610_PRODUCT_ID) {
        LOG_WRN("PMW3610 pointer product id mismatch: 0x%02x", product_id);
        return false;
    }
#endif

    return true;
}

static void error_blink_handler(struct k_work *work) {
    if (!health_error) {
        error_blink_on = false;
        (void)set_led(&red_led, false);
        return;
    }

    error_blink_on = !error_blink_on;
    (void)set_led(&red_led, error_blink_on);

    k_work_schedule(&error_blink_work,
                    K_MSEC(CONFIG_CLICKTAPTOE_STATUS_LED_ERROR_BLINK_MS));
}

static void set_health_state(bool error) {
    if (health_initialized && error == health_error) {
        return;
    }

    health_initialized = true;
    health_error = error;

    if (error) {
        error_blink_on = false;
        (void)set_led(&green_led, false);
        k_work_reschedule(&error_blink_work, K_NO_WAIT);
    } else {
        (void)k_work_cancel_delayable(&error_blink_work);
        error_blink_on = false;
        (void)set_led(&red_led, false);
        (void)set_led(&green_led, true);
    }
}

static void health_check_handler(struct k_work *work) {
    set_health_state(!required_devices_ready());
    k_work_schedule(&health_check_work,
                    K_MSEC(CONFIG_CLICKTAPTOE_STATUS_LED_HEALTH_CHECK_MS));
}

static void activity_off_handler(struct k_work *work) { (void)set_led(&blue_led, false); }

static void pulse_activity_led(void) {
    (void)set_led(&blue_led, true);
    k_work_reschedule(&activity_off_work,
                      K_MSEC(CONFIG_CLICKTAPTOE_STATUS_LED_ACTIVITY_PULSE_MS));
}

static bool sensor_event_has_value(const struct zmk_sensor_event *event) {
    for (int i = 0; i < event->channel_data_size; i++) {
        struct sensor_value value = event->channel_data[i].value;

        if (value.val1 != 0 || value.val2 != 0) {
            return true;
        }
    }

    return false;
}

static int status_led_event_listener(const zmk_event_t *eh) {
    const struct zmk_position_state_changed *position_event = as_zmk_position_state_changed(eh);

    if (position_event != NULL) {
        pulse_activity_led();
        return ZMK_EV_EVENT_BUBBLE;
    }

    const struct zmk_sensor_event *sensor_event = as_zmk_sensor_event(eh);

    if (sensor_event != NULL && sensor_event_has_value(sensor_event)) {
        pulse_activity_led();
    }

    return ZMK_EV_EVENT_BUBBLE;
}

ZMK_LISTENER(clicktaptoe_status_led, status_led_event_listener);
ZMK_SUBSCRIPTION(clicktaptoe_status_led, zmk_position_state_changed);
ZMK_SUBSCRIPTION(clicktaptoe_status_led, zmk_sensor_event);

#if DT_NODE_HAS_STATUS(PMW3610_NODE, okay)
static void pmw3610_input_callback(struct input_event *event, void *user_data) {
    if (event->type == INPUT_EV_REL && event->value != 0) {
        pulse_activity_led();
    }
}

INPUT_CALLBACK_DEFINE(DEVICE_DT_GET(PMW3610_NODE), pmw3610_input_callback, NULL);
#endif
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

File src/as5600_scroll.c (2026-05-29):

/*
 * Copyright (c) 2026 ClickTapToe contributors
 *
 * SPDX-License-Identifier: MIT
 */

#define DT_DRV_COMPAT clicktaptoe_as5600_scroll

#include <stdlib.h>

#include <zephyr/device.h>
#include <zephyr/drivers/i2c.h>
#include <zephyr/drivers/sensor.h>
#include <zephyr/kernel.h>
#include <zephyr/logging/log.h>
#include <zephyr/sys/byteorder.h>
#include <zephyr/sys/util.h>

LOG_MODULE_REGISTER(clicktaptoe_as5600_scroll, CONFIG_CLICKTAPTOE_AS5600_SCROLL_LOG_LEVEL);

#define AS5600_RAW_ANGLE_REGISTER 0x0C
#define AS5600_STATUS_REGISTER 0x0B
#define AS5600_COUNTS_PER_REV 4096
#define AS5600_HALF_REV_COUNTS (AS5600_COUNTS_PER_REV / 2)
#define AS5600_FULL_ROTATION_DEGREES 360
#define AS5600_MICRO_UNITS 1000000
#define AS5600_MIN_REPORT_COUNTS DIV_ROUND_UP(AS5600_COUNTS_PER_REV, AS5600_FULL_ROTATION_DEGREES)

#define AS5600_STATUS_MH_BIT 3
#define AS5600_STATUS_ML_BIT 4
#define AS5600_STATUS_MD_BIT 5
#define AS5600_STATUS_MAGNET_MASK                                                                  \
    (BIT(AS5600_STATUS_MH_BIT) | BIT(AS5600_STATUS_ML_BIT) | BIT(AS5600_STATUS_MD_BIT))

struct as5600_scroll_config {
    struct i2c_dt_spec i2c;
    uint16_t poll_ms;
    uint16_t deadband;
    bool invert;
};

struct as5600_scroll_data {
    const struct device *dev;
    struct k_work_delayable poll_work;
    sensor_trigger_handler_t handler;
    const struct sensor_trigger *trigger;
    int16_t last_position;
    int32_t pending_counts;
    int last_error;
    uint8_t last_status;
    bool has_position;
    bool has_status;
    bool has_error;
};

static void as5600_scroll_record_error(struct as5600_scroll_data *data, const char *message,
                                       int err) {
    if (!data->has_error || data->last_error != err) {
        LOG_WRN("%s: %d", message, err);
    }

    data->has_error = true;
    data->last_error = err;
}

static int as5600_scroll_read_status(const struct device *dev, uint8_t *status) {
    const struct as5600_scroll_config *config = dev->config;

    return i2c_reg_read_byte_dt(&config->i2c, AS5600_STATUS_REGISTER, status);
}

static int as5600_scroll_check_status(const struct device *dev) {
    struct as5600_scroll_data *data = dev->data;
    uint8_t status;
    int err = as5600_scroll_read_status(dev, &status);

    if (err) {
        as5600_scroll_record_error(data, "Failed to read AS5600 status", err);
        return err;
    }

    uint8_t magnet_status = status & AS5600_STATUS_MAGNET_MASK;
    bool status_changed = !data->has_status || magnet_status != data->last_status;

    data->has_status = true;
    data->last_status = magnet_status;

    if (!(status & BIT(AS5600_STATUS_MD_BIT))) {
        if (status_changed) {
            LOG_WRN("AS5600 magnet not detected");
        }
        return -ENODATA;
    }

    if (status & BIT(AS5600_STATUS_MH_BIT)) {
        if (status_changed) {
            LOG_WRN("AS5600 magnet too strong");
        }
        return -ENODATA;
    }

    if (status & BIT(AS5600_STATUS_ML_BIT)) {
        if (status_changed) {
            LOG_WRN("AS5600 magnet too weak");
        }
        return -ENODATA;
    }

    return 0;
}

static int as5600_scroll_read_position(const struct device *dev, uint16_t *position) {
    const struct as5600_scroll_config *config = dev->config;
    uint8_t buffer[2] = {0};
    int err = i2c_burst_read_dt(&config->i2c, AS5600_RAW_ANGLE_REGISTER, buffer, sizeof(buffer));

    if (!err) {
        *position = sys_get_be16(buffer) & 0x0FFF;
    }

    return err;
}

static int as5600_scroll_update(const struct device *dev) {
    struct as5600_scroll_data *data = dev->data;
    const struct as5600_scroll_config *config = dev->config;
    uint16_t position;
    int err = as5600_scroll_check_status(dev);

    if (err) {
        data->has_position = false;
        return err;
    }

    err = as5600_scroll_read_position(dev, &position);
    if (err) {
        as5600_scroll_record_error(data, "Failed to read AS5600 angle", err);
        return err;
    }

    data->has_error = false;

    if (!data->has_position) {
        data->last_position = position;
        data->has_position = true;
        return 0;
    }

    int16_t delta = (int16_t)position - data->last_position;

    if (delta > AS5600_HALF_REV_COUNTS) {
        delta -= AS5600_COUNTS_PER_REV;
    } else if (delta < -AS5600_HALF_REV_COUNTS) {
        delta += AS5600_COUNTS_PER_REV;
    }

    data->last_position = position;

    if (delta == 0 || abs(delta) <= config->deadband) {
        return 0;
    }

    data->pending_counts += config->invert ? -delta : delta;

    LOG_DBG("position %u delta %d pending %d", position, delta, data->pending_counts);
    return 0;
}

static void as5600_scroll_poll(struct k_work *work) {
    struct k_work_delayable *delayable = k_work_delayable_from_work(work);
    struct as5600_scroll_data *data = CONTAINER_OF(delayable, struct as5600_scroll_data, poll_work);
    const struct device *dev = data->dev;
    const struct as5600_scroll_config *config = dev->config;
    int32_t pending_before = data->pending_counts;

    (void)as5600_scroll_update(dev);

    /* ZMK treats val1 == 0 rotation reports as legacy EC11 ticks, so only notify once the
     * accumulated AS5600 delta can be reported as at least one whole degree.
     */
    if (data->handler && abs(data->pending_counts) >= AS5600_MIN_REPORT_COUNTS &&
        data->pending_counts != pending_before) {
        data->handler(dev, data->trigger);
    }

    k_work_schedule(&data->poll_work, K_MSEC(config->poll_ms));
}

static int as5600_scroll_sample_fetch(const struct device *dev, enum sensor_channel chan) {
    if (chan != SENSOR_CHAN_ALL && chan != SENSOR_CHAN_ROTATION) {
        return -ENOTSUP;
    }

    return 0;
}

static int as5600_scroll_channel_get(const struct device *dev, enum sensor_channel chan,
                                     struct sensor_value *val) {
    struct as5600_scroll_data *data = dev->data;
    int32_t counts = data->pending_counts;

    if (chan != SENSOR_CHAN_ROTATION) {
        return -ENOTSUP;
    }

    data->pending_counts = 0;

    int64_t microdegrees =
        ((int64_t)counts * AS5600_FULL_ROTATION_DEGREES * AS5600_MICRO_UNITS) /
        AS5600_COUNTS_PER_REV;

    val->val1 = microdegrees / AS5600_MICRO_UNITS;
    val->val2 = microdegrees % AS5600_MICRO_UNITS;

    return 0;
}

static int as5600_scroll_trigger_set(const struct device *dev, const struct sensor_trigger *trigger,
                                     sensor_trigger_handler_t handler) {
    struct as5600_scroll_data *data = dev->data;

    if (trigger->type != SENSOR_TRIG_DATA_READY || trigger->chan != SENSOR_CHAN_ROTATION) {
        return -ENOTSUP;
    }

    data->trigger = trigger;
    data->handler = handler;

    return 0;
}

static const struct sensor_driver_api as5600_scroll_api = {
    .trigger_set = as5600_scroll_trigger_set,
    .sample_fetch = as5600_scroll_sample_fetch,
    .channel_get = as5600_scroll_channel_get,
};
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

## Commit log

2026-04-29 Add EC11 scroll wheel firmware functionality
2026-04-30 Implemented PMW3610 for mouse pointing, disabled bluetooth, checked functionality with ethernet cable
2026-05-14 chore: standardize project workflow and hardware structure
    - Rename hardware
    folders around input-hub and mouse-pointer boards.
    - Add hardware placeholder structure for
    source and production outputs.
    - Add CONTRIBUTING.md with commit, branch, release, and changelog
    conventions.
    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
2026-05-14 feat: import mouse pointer board baseline
    - Import the cleaned PMW3610 KiCad
    project as the mouse-pointer board baseline.
    - Rename KiCad project files and local symbol/
    footprint libraries to use mouse_pointer naming.
    - Preserve the upstream CERN-OHL-P v2 license
    and attribution notice.
    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
    [mouse_pointer.kicad_pcb, mouse_pointer.kicad_sch]
2026-05-14 chore: refresh standard KiCad library footprints
    - Update standard
    passive, mounting hole, regulator, and header footprints from the KiCad 10 libraries.
    - Preserve
    custom mouse-pointer footprints and JLC assembly metadata.
    [mouse_pointer.kicad_pcb]
2026-05-14 fix: resolve mouse pointer schematic ERC errors
    - Correct PMW3610 internal
    support pin electrical types.
    - Add power flags for VIN, GND, and VDDIO.
    [mouse_pointer.kicad_sch]
2026-05-14 chore: refresh standard KiCad schematic symbols
    - Update standard resistor
    and solder jumper symbols from the KiCad 10 libraries.
    - Exclude solder jumpers from the BOM
    because they are PCB copper features, not assembled parts.
    - Preserve schematic fields and JLC
    assembly metadata.
    - Resolve remaining symbol library mismatch warnings.
    [mouse_pointer.kicad_sch]
2026-05-14 feat: add RJ45 mouse pointer board interface
    - Add the ClickTapToe 8P8C/RJ45 pinout to the PMW3610 mouse pointer board.
    - Add reset and VDDIO configuration links, optional nCS pull-up, and MOTION series resistor.
    - Extend the board layout for the RJ45 connector and added mounting holes.
    - Document revised mouse pointer cabling, twisted-pair grouping, and input hub wiring contract.
    [mouse_pointer.kicad_pcb, mouse_pointer.kicad_sch]
2026-05-14 docs: add mouse pointer KiCanvas viewer
    - Add a browser-based KiCanvas page for reviewing the mouse pointer schematic and PCB.
    - Document the GitHub Pages URL for sharing the board preview.
2026-05-18 feat: validate input hub pin reassignment
    - Move the EC11 scroll encoder from D2/D3 to D4/D5.
    - Add D2/D3 as test GPIO inputs for play/pause and volume up.
    - Reserve D6 for PMW3610 nRESET without wiring it into firmware.
    - Keep PMW3610 SPI pins unchanged and document the test pin plan.
    - Move local ZMK build output under this repo to avoid stale app builds.
2026-05-18 fix: calibrate scroll encoder for PEC11R
    - Set EC11 steps for the PEC11R-4215F-S0024 quadrature transition count.
    - Trigger scroll once per 24-detent rotation step.
    - Document the selected encoder part and ZMK calibration values.
2026-05-18 fix: refine mouse pointer board layout
    - Adjust board outline edges.
    - Reposition components for improved decoupling
    - Tune trace routing and via placement
    [mouse_pointer.kicad_pcb]
2026-05-18 feat: add input hub board draft
    - Add the XIAO nRF52840 input hub KiCad
    project.
    - Route the PMW3610 RJ45 interface with ESD protection and source-side series parts.
    - Add EC11 and AS5600 scroll input options plus pedal, footswitch, and battery connectors.
    - Include local symbols, footprints, 3D models, and JLC/DigiKey sourcing fields.
    [102010448.step, ACJMIH.step, BM04B-SRSS-TB_LF__SN_.step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]
2026-05-21 fix: refine input hub board draft
    Update the input hub KiCad design after
    layout review.
    - Replace solder fallback headers with standard 2.54 mm footprints.
    - Clean up PMW3610 RJ45 routing, ESD placement, and local power conditioning.
    - Add optional SJ1-3523N 3.5 mm jack library assets for future pedal jack variants.
    - Preserve AS5600, EC11, footswitch, battery, and PMW3610 interface options for review.
    [SJ1-3523N.step, input_hub.kicad_pcb, input_hub.kicad_sch]
2026-05-21 fix: refine input hub battery layout
    - Update the battery connector layout.
    - Rename the battery connector from P to J.
    - Add return vias near signal vias.
    - Widen power-path traces.
    - Add XIAO battery solder holes and silkscreen labels.
    [input_hub.kicad_pcb, input_hub.kicad_sch]
2026-05-22 fix: make input hub routing more gooder and a schematic change - esd routing and schematic - PEC11R debounce circuit - reduced back side routing - added filter caps to 1/4 inch jacks - made traces th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
    [input_hub.kicad_pcb, input_hub.kicad_sch]
2026-05-29 feat: add AS5600 scroll sensor support
    - Add a ClickTapToe AS5600 scroll driver for ZMK rotation events.
    - Replace the EC11 scroll path with AS5600 over the XIAO I2C bus.
    - Update hardware and build docs for the magnetic scroll wheel.
    [as5600_scroll.c]
2026-05-29 feat: add ESD protection to mouse pointer and update board fields
    - Add ESD protection, logo artwork, and final board manufacturing fields.
    - Include generated fabrication outputs for direct ordering.
    - Document hand-installed RJ45, optional tester header, and board configuration.
    [TPD4E05U06DQAR.step, bom.csv, designators.csv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]
2026-05-30 feat: add PJ-307 alternate pedal jacks
    - Import the HOOYA PJ-307/C2939173 symbol, footprint, and STEP model.
    - Replace the stale SJ1-3523N library assets with the PJ-307 part.
    - Add 3.5 mm alternate pedal jack footprints under the 1/4 in pedal jacks.
    - Update silkscreen labels and artwork
    [AUDIO-TH_PJ-307.step, SJ1-3523N.step, input_hub.kicad_pcb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]
2026-06-01 feat: remove input hub EC11 encoder and update 3D models
    - Remove the EC11 encoder and supporting debounce network from the input hub.
    - Add project-local 3D model links for imported input hub footprints.
    - Vendor the RJ45 footprint with the exact Amphenol 54602-908LF model.
    - Add the XIAO battery solder access symbol and footprint.
    [54602-908LFc.stp, input_hub.kicad_pcb, input_hub.kicad_sch]
2026-06-01 feat: remove third TS jack and make vertical JST battery connector
    - Remove the third pedal jack option to reduce board width.
    - Align edge connectors for a cleaner enclosure-facing layout.
    - Replace the horizontal battery JST with a vertical B2B-PH-SM4-TB footprint.
    - Remove stale horizontal JST symbol, footprint, and model assets.
    [B2B-PH-SM4-TB.step, S2B-PH-SM4-TB_LF__SN_.step, input_hub.kicad_pcb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]
2026-06-02 docs: clarify PMW3610 reset and motion routing
    - Document MOTION on XIAO D7
    and RJ45 pin 7 as the implemented PMW3610 interrupt.
    - Document nRESET on XIAO D6 and RJ45 pin 8 as physically routed but not firmware-driven yet.
    - Remove stale third pedal jack and unrouted reset references from bring-up notes.
    - Keep the input hub, mouse pointer, hardware map, and overlay comments in sync.
2026-06-02 feat: updated board for JLC constraints, add 3D models, add silkscreen logos, correct production outputs
    - Add Cal Poly and EMPOWER silkscreen artwork and generated KiCad footprints.
    - Add PMW3610 and RJ45 model assets for board review.
    - Update JLC board constraints and clean up resulting DRC issues.
    - Update ESD placement rotation fields for JLC assembly output.
    - Exclude optional headers, RJ45s, DNP parts, test points, and holes from assembly files.
    - Regenerate mouse pointer production BOM, CPL, netlist, and fabrication archive.
    [54602-908LFc.stp, PMW3610DM-SUDU.step, bom.csv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]
2026-06-02 chore: set mouse pointer board revision to 1.0
    - Mark Mouse Pointer 1.0 as the first ClickTapToe-maintained production revision.
    - Replace the old Mouse_Pointer_3.0 fabrication archive with Mouse_Pointer_1.0.
    - Update hardware notes for the current reset routing and firmware behavior.
    [mouse_pointer.kicad_pcb, mouse_pointer.kicad_sch]
2026-06-03 feat: prep input hub for JLC assembly
    - Add JLC-oriented board constraints, DRC exclusions, revised vias, and production metadata.
    - Add input hub 3D model links, silkscreen logos, PJ-307 footprint updates, and vertical battery
    JST metadata.
    - Route/document PMW3610 reset and MOTION pull-up support with firmware retry configuration.
    - Clean up remaining EC11 encoder library artifacts and stale encoder nets.
    [PEC11R-4215F-S0024.step, input_hub.kicad_pcb, input_hub.kicad_sch]
2026-06-11 fix: validate working config with input hub PCB
    Validated the input hub PCB
    with the current PMW3610 cable pinout, series resistors, and MOT pull-up using the original SPI
    reset driver path.
    - Switch pedal GPIOs to active-high for normally-closed Yamaha-style pedals.
    - Document the PCB-validated PMW3610 wiring and D6 reset routing.
    - Leave PMW3610 hardware reset/retry firmware work out of this checkpoint.
2026-06-11 feat: add XIAO onboard status activity LED
    - Use the XIAO BLE onboard RGB LED
    for firmware health and activity status.
    - Show green when AS5600 and PMW3610 health checks pass.
    - Blink red when a required device is missing or unresponsive.
    - Pulse blue for pedal, scroll, and pointer activity.
    [status_led.c]
2026-06-11 feat: add input hub KiCanvas preview
    - Add a KiCanvas preview page for the
    input hub KiCad project.
    - Link both hardware board previews from the main README.
    - Document the input hub preview URL in the board README.
    - Note the next input hub pedal jack normal-contact grounding improvement.
2026-06-11 feat: add public hardware viewer page
    - Add a GitHub Pages hardware viewer
    with board images, KiCanvas embeds, downloads, and assembly guidance.
    - Export static SVG previews for the input hub and mouse pointer boards.
    - Add a combined electronics BOM CSV for one complete board set.
    - Link the public viewer from the main README.
    [clicktaptoe-electronics-bom.csv]
2026-06-11 docs: prep hardware branch for main merge
    - Summarize the merge-ready
    firmware, hardware, and documentation work in the changelog.
    - Add next-step notes for the deferred PMW3610 reset-retry driver stash.
    - Note the stashed XIAO battery access footprint for a future input hub hardware update.
    - Track the tested ClickTapToe UF2 while keeping local build outputs ignored.
    - Clean up README references for the current firmware and tracked firmware artifact.
2026-06-11 chore: tune GitHub language detection
    - Mark KiCad hardware source files as
    detectable for GitHub Linguist.
    - Exclude generated hardware previews, production outputs, 3D models, and firmware artifacts from
    language stats.
2026-06-11 chore: refine GitHub language detection
    - Count KiCad board and schematic
    files in GitHub Linguist.
    - Treat inherited KiCad footprint and symbol libraries as vendored support files.
    - Keep generated exports and firmware artifacts out of language stats.
2026-06-16 fix: add input hub pedal normal jumpers
    - Route pedal jack normal contacts
    through optional 0R jumpers to ground.
    - Use existing 0603 0R jumper sourcing for the new input hub build options.
    - Track release-ready input hub fabrication outputs for ordering.
    [bom.csv, designators.csv, input_hub.kicad_pcb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]

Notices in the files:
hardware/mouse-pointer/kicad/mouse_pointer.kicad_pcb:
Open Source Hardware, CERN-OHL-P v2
